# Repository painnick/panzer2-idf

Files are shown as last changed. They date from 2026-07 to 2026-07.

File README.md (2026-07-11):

# panzer2-idf

ESP32-C3 기반 RC 탱크 펌웨어입니다.  
BLE 게임패드로 **캐터필러 주행**, **터렛 회전**, **포/기관총 효과**, **DFPlayer 효과음**을 제어합니다.

Arduino/PlatformIO 프로젝트 **M3Stuart_ESP32C3** 를 ESP-IDF v5.5.2 로 포팅한 버전이며, 입력은 [Bluepad32](https://github.com/ricardoquesada/bluepad32) + BTstack 를 사용합니다.

## 기능

| 기능 | 설명 |
|---|---|
| 트랙 구동 | DRV8833, 좌/우 스틱 Y축 — panzer4식 가속/감속 램프(~1초 최대) |
| 터렛 | SG90 서보 — 패드 연결 시 attach, D-Pad 좌우 회전, 3초 무입력/해제 시 detach |
| 포신 | B 버튼 — LED·효과음 후 트랙 후진 리코일 |
| 게틀링(기관총) | A 버튼 — 게틀링 LED 깜빡임 + 효과음 |
| 볼륨 | L1 / R1, NVS에 저장 |
| 사운드 | DFPlayer Mini (대기 / 포 / 기관총 / 연결음) |

## 하드웨어

- **MCU**: ESP32-C3 (BLE only — Classic BT 미지원)
- **모터 드라이버**: DRV8833
- **서보**: SG90 (터렛)
- **오디오**: DFPlayer Mini + microSD
- **입력**: BLE HID 게임패드 (검증: GamePadPlus V3 / ShanWan BM-769)

### 핀맵

| 기능 | GPIO |
|---|---|
| 좌측 트랙 IN1 / IN2 | 4 / 3 |
| 우측 트랙 IN1 / IN2 | 0 / 5 |
| 포신 LED | 1 |
| 게틀링 LED | 6 |
| 터렛 서보 | 7 |
| DFPlayer TX / RX | 10 / 9 |

> GPIO20/21은 ESP32-C3 기본 UART0 콘솔용입니다. DFPlayer RX는 **GPIO9**를 사용합니다.

### PCB

회로 개략도는 `pcb/` 에 있습니다.

| 파일 | 설명 |
|---|---|
| `pcb/Schematic_M3-Stuart_2026-07-11.png` | M3 Stuart 스케매틱 |

### 3D 출력 (`3dp/`)

기구부 STEP 모델입니다. 슬라이서에서 열어 STL 등으로 변환해 출력하면 됩니다.

| 파일 | 설명 |
|---|---|
| `Idler.step` | 아이들러 |
| `Motor Guide 2mm.step` | 모터 가이드 2mm |
| `Motor Guide 3mm D.step` | 모터 가이드 3mm |
| `PCB 3.2.step` | PCB 브라켓 |
| `Sproket Guide.step` | 스프로킷 가이드 |
| `Turret.step` | 터렛 |

### DFPlayer 트랙 (SD 카드)

| 파일 | 용도 |
|---|---|
| `0001.mp3` | 대기 루프 |
| `0002.mp3` | 포신 발사 |
| `0003.mp3` | 기관총 |
| `0004.mp3` | 게임패드 연결 |

## 조작

| 입력 | 동작 |
|---|---|
| 좌 스틱 Y | 좌측 트랙 전/후진 (즉시 최대 아님, ~1초 램프 가속) |
| 우 스틱 Y | 우측 트랙 전/후진 (동일) |
| D-Pad ← / → | 터렛 좌/우 회전 (0°~180°, 약 120ms마다 1°) |
| Start | 터렛 서보 중앙(90°) |
| A | 게틀링(기관총) — LED 75ms 깜빡임, 약 0.5초 |
| B | 포신 — LED·효과음 후 리코일(후진) |
| L1 / R1 | 볼륨 감소 / 증가 |

### 터렛 서보

- **부팅**: 서보 미연결 (PWM 없음)
- **게임패드 연결 시**: 서보 attach 후 **중앙(90°)** 설정
- **게임패드 해제 시**: 서보 detach
- **회전 속도**: `TURRET_STEP_INTERVAL_MS`(기본 120ms)마다 1° — 전체 0°↔180°에 약 22초
- **무입력 해제**: D-Pad 터렛 입력이 `TURRET_IDLE_DISCONNECT_MS`(기본 **3초**) 없으면 detach (버즈·홀딩 전류 감소)
- **재연결**: D-Pad 좌/우로 각도를 바꿀 때 다시 attach

### 포 발사 시퀀스 (B)

1. 포신 LED ON + 포 효과음 재생
2. `RECOIL_DELAY_MS`(기본 250ms) 대기
3. 트랙 후진 리코일 (`RECOIL_BACK_DURATION` 40ms) → 정지 안정화 (`RECOIL_SETTLE_DURATION` 40ms)

스틱 전진이 음수 축이므로 리코일 후진은 양수 모터 속도(`RECOIL_BACK_SPEED`)를 사용합니다. 리코일 중에는 스틱 모터 입력을 잠시 무시합니다.

## 게임패드 연결 (중요)

ESP32-C3는 **BLE만** 지원합니다. DualShock 등 Classic BT 전용 패드는 연결되지 않습니다.

### GamePadPlus V3 / Terios T3 / ShanWan BM-769

1. 패드를 끈 뒤, **`Home + X`** 를 약 3초 눌러 페어링 모드로 진입 (표준 Android BLE HID)
2. 펌웨어 부팅 후 자동 스캔·연결
3. 성공 시 로그 예: `Gamepad ready (...), reports=2` → `게임패드 연결됨`

`Home + A` / `Home + Y` 모드는 BLE여도 HID 데이터 형식이 달라 동작하지 않을 수 있습니다.

### 연결 구현 메모

일부 저가 BLE 패드는 BTstack 기본 `hids_client` 경로에서 HID 설정이 멈추는 문제가 있습니다.  
이 프로젝트는 **Simple HOG** 경로를 사용합니다.

- GATT 서비스 탐색 → HID(0x1812) 특성 탐색
- Report Map 읽기
- CCC 직접 쓰기 + 알림 수신
- Report ID 프리펜드 후 Bluepad32 Android 파서로 입력 처리

부팅 시 본딩 키를 지우지 않습니다. 강제 재페어링이 필요하면 콘솔에서 키 삭제 명령을 사용하세요.

## 소프트웨어 구조

```
main/
  main.c           # 모터/서보/LED, 게임패드 처리, 제어 루프
  my_platform.c    # Bluepad32 커스텀 플랫폼, 공유 입력 상태
  dfplayer.c/.h    # DFPlayer Mini UART 제어
components/
  bluepad32/       # Bluepad32 (커스텀 Simple HOG 포함)
  btstack/         # BTstack ESP32 포트
```

- **bt_main**: BTstack 런 루프 (우선순위 높음)
- **tank_ctrl**: 10ms 주기로 게임패드 입력 → 액추에이터 반영

## 빌드 & 플래시

### 요구 사항

- [ESP-IDF v5.5.x](https://docs.espressif.com/projects/esp-idf/en/v5.5.2/esp32c3/get-started/index.html)
- 타깃: `esp32c3`

### 환경 설정 (Windows 예)

```bat
REM ESP-IDF export (경로는 설치에 맞게 수정)
call C:\Espressif\frameworks\esp-idf-v5.5.2\export.bat

cd panzer2-idf
idf.py set-target esp32c3
idf.py build
idf.py -p COMx flash monitor
```

`setup.bat` / `setup.sh` 로 Bluepad32·BTstack 의존성을 준비할 수 있습니다 (이미 `components/` 가 포함되어 있으면 생략 가능).

### 주요 sdkconfig

- BLE 컨트롤러 only (`CONFIG_BT_CONTROLLER_ONLY`)
- Wi-Fi 비활성
- Bluepad32 커스텀 플랫폼
- 기본 로그 레벨: INFO (상세 BLE 단계는 DEBUG)

## 라이선스 관련

- 애플리케이션 코드: 프로젝트 정책에 따름
- **Bluepad32**: Apache-2.0
- **BTstack**: 비상업 평가 가능, 상업 사용 시 [BlueKitchen](https://bluekitchen-gmbh.com/) 라이선스 필요

## 참고

- [Bluepad32 문서](https://bluepad32.readthedocs.io/)
- [ESP-IDF](https://docs.espressif.com/projects/esp-idf/)
- 원본: M3Stuart_ESP32C3 (Arduino/PlatformIO)

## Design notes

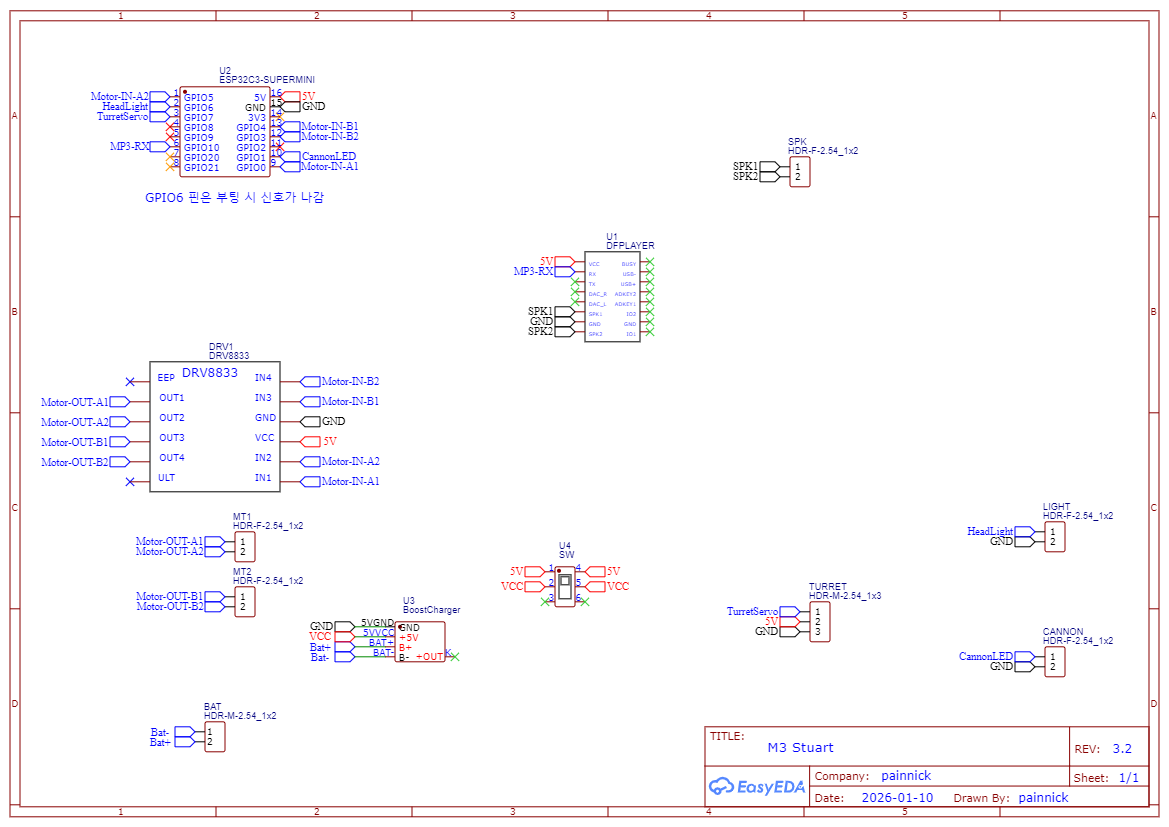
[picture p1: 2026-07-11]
pcb/Schematic_M3-Stuart_2026-07-11.png

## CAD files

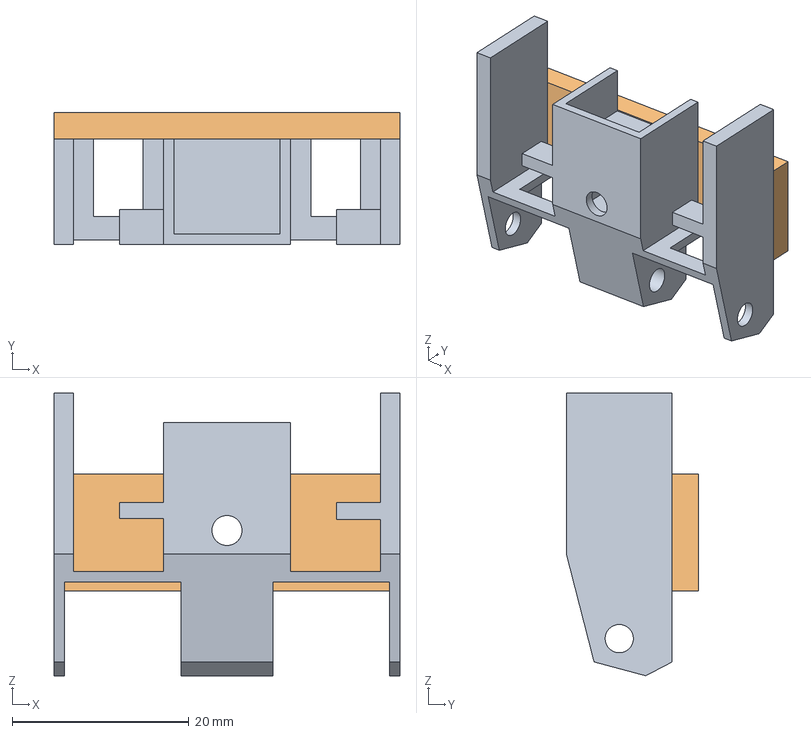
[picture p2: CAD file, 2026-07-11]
3dp/Sproket Guide.step
39.2 x 15.0 x 32.0 mm

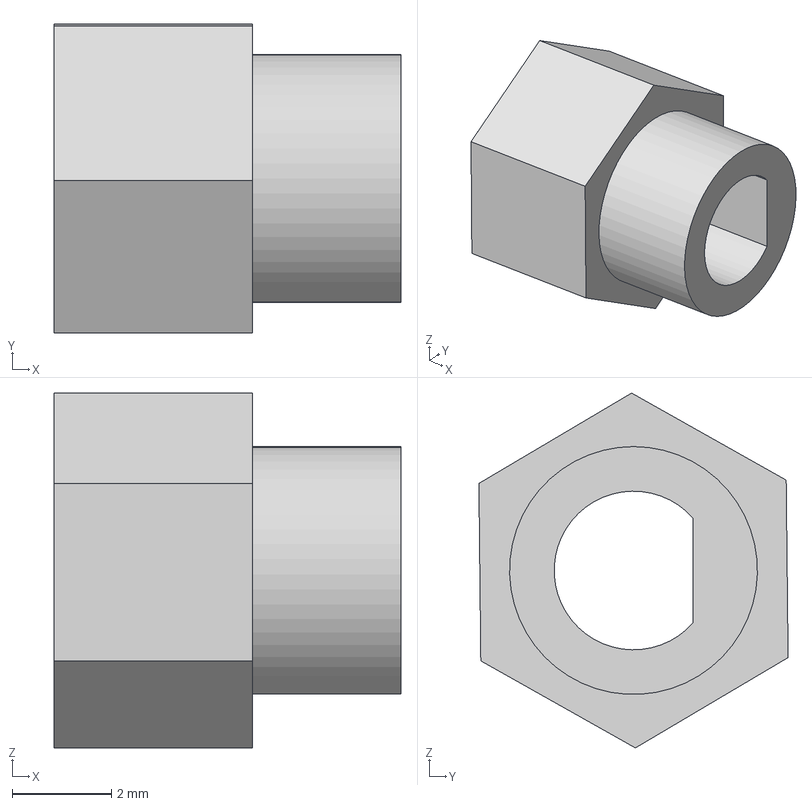
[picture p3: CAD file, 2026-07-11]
3dp/Motor Guide 3mm D.step
7.00 x 6.24 x 7.16 mm

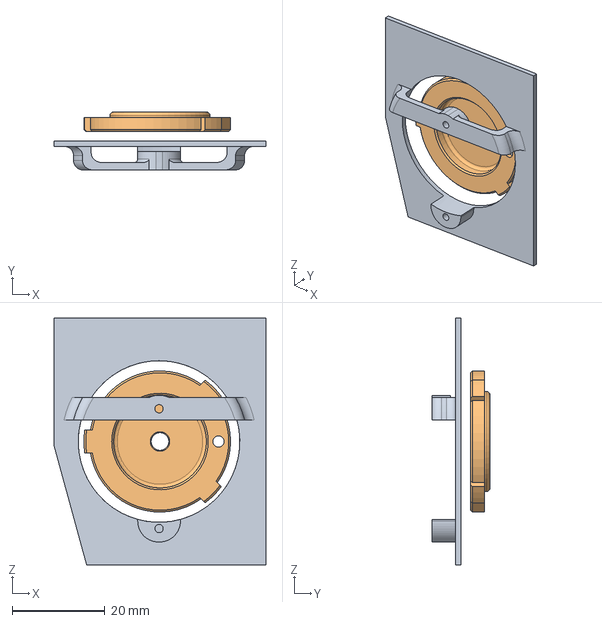
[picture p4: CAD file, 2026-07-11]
3dp/Turret.step
45.6 x 12.5 x 53.2 mm
Cover

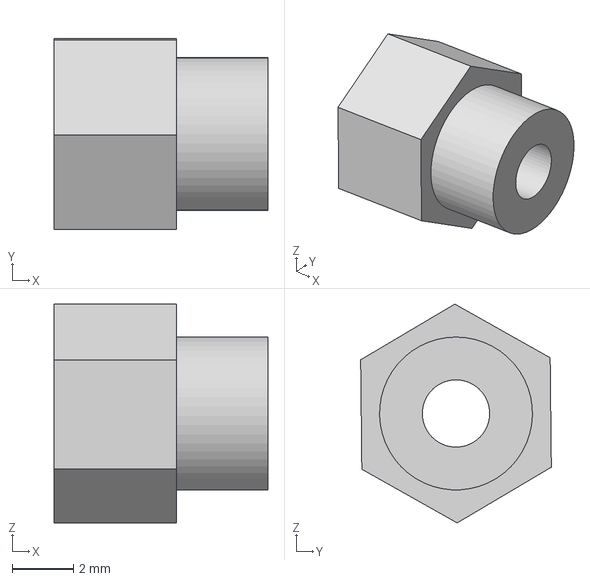
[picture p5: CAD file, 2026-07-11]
3dp/Motor Guide 2mm.step
7.00 x 6.24 x 7.16 mm

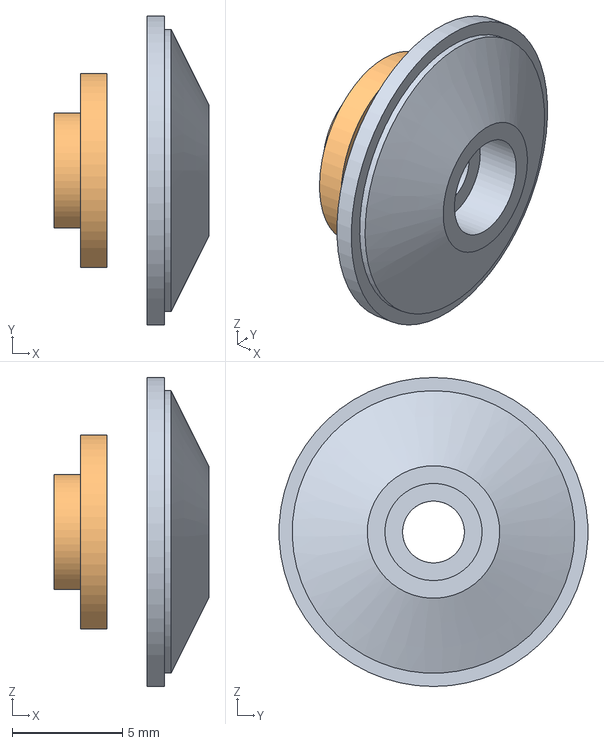
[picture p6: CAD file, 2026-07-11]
3dp/Idler.step
7.00 x 14.0 x 14.0 mm

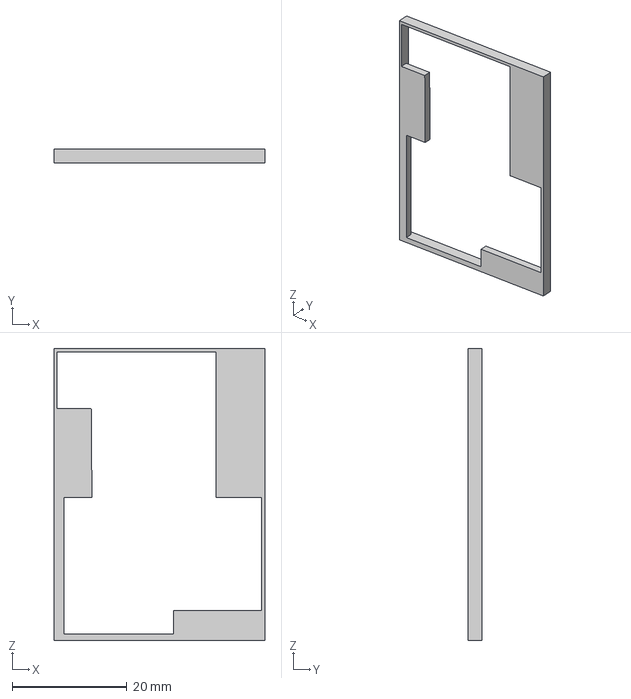
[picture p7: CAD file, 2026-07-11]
3dp/PCB 3.2.step
36.7 x 2.40 x 50.8 mm

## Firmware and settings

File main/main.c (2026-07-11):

// RC 탱크 - ESP-IDF v5.5.2
// Original: M3Stuart_ESP32C3 (Arduino/PlatformIO)
//
// Bluepad32 게임패드로 DRV8833 모터 트랙 + SG90 서보 터렛 + DFPlayer 효과음 제어

#include <string.h>
#include <math.h>

#include "freertos/FreeRTOS.h"
#include "freertos/task.h"
#include "esp_log.h"
#include "esp_timer.h"
#include "nvs_flash.h"
#include "nvs.h"
#include "driver/gpio.h"
#include "driver/ledc.h"

#include "btstack_port_esp32.h"
#include "dfplayer.h"
#include "btstack_run_loop.h"
#include "uni.h"

// my_platform.c
struct uni_platform* get_my_platform(void);
void gamepad_state_init(void);

static const char* TAG = "RC_TANK";

// ============================================================================
// 핀 정의
// ============================================================================
#define PIN_LEFT_IN1        4   // DRV8833 좌측 트랙 IN1
#define PIN_LEFT_IN2        3   // DRV8833 좌측 트랙 IN2
#define PIN_RIGHT_IN1       0   // DRV8833 우측 트랙 IN1
#define PIN_RIGHT_IN2       5   // DRV8833 우측 트랙 IN2
#define PIN_CANNON_LED      1   // 포신 LED
#define PIN_MG_LED          6   // 게틀링(기관총) LED
#define PIN_TURRET_SERVO    7   // 터렛 SG90 서보

// ============================================================================
// LEDC 채널/타이머 할당
// ============================================================================
#define LEDC_MOTOR_FREQ     5000
#define LEDC_MOTOR_RES      LEDC_TIMER_8_BIT
#define LEDC_SERVO_FREQ     50
#define LEDC_SERVO_RES      LEDC_TIMER_14_BIT

#define LEDC_CH_LEFT_IN1    LEDC_CHANNEL_0
#define LEDC_CH_LEFT_IN2    LEDC_CHANNEL_1
#define LEDC_CH_RIGHT_IN1   LEDC_CHANNEL_2
#define LEDC_CH_RIGHT_IN2   LEDC_CHANNEL_3
#define LEDC_CH_SERVO       LEDC_CHANNEL_4

#define LEDC_TIMER_MOTOR    LEDC_TIMER_0
#define LEDC_TIMER_SERVO    LEDC_TIMER_1

// ============================================================================
// NVS 키
// ============================================================================
#define NVS_NAMESPACE       "rc_tank"
#define NVS_KEY_VOLUME      "volume"

// ============================================================================
// 타이밍 상수 (ms)
// ============================================================================
#define LOOP_INTERVAL_MS        10
#define IDLE_SOUND_INTERVAL_MS  13000
#define VOLUME_CHANGE_INTERVAL  100
#define BUTTON_SWAP_HOLD_MS     3000
#define EEPROM_RESET_HOLD_MS    3000
#define CANNON_LED_DURATION     200
#define MACHINE_GUN_DURATION    500   // panzer4 MG_FIRE_MS
#define MG_LED_BLINK_MS         75    // panzer4 게틀링 LED 깜빡임 주기
#define TURRET_STEP_INTERVAL_MS 120   // 터렛 1° 이동 간격 (ms) — 아주 느리게
#define TURRET_IDLE_DISCONNECT_MS 3000 // 터렛 무입력 시 서보 연결 해제 (ms)
#define GAMEPAD_CONNECT_GRACE_MS  500 // 연결 직후 입력 무시 (노이즈/잔여 D-Pad 방지)
#define RECOIL_DELAY_MS         250   // LED·효과음 후 반동 시작 지연 (ms)
#define RECOIL_BACK_DURATION    40    // 포 발사 시 후진 시간 (ms)
#define RECOIL_SETTLE_DURATION  40    // 후진 후 정지 안정화 (ms)

// ============================================================================
// 모터 설정 (panzer4: 램프 가속/감속)
// ============================================================================
// 기동 최소 속도 (0~512). 너무 낮으면 고주파 윙 소리만 나고 바퀴가 안 돔.
// duty ≈ START * 255 / 512 → 400 ≈ 78%
#define MOTOR_START_SPEED   400
#define MOTOR_MAX_SPEED     512
#define LEDC_MOTOR_DUTY_MAX 255   // 8-bit LEDC
// 내부 속도 = 실제 속도 * TRACK_SPEED_SCALE (10ms마다 step)
// 기동(START)→max 약 1초, max→정지 약 0.4초
#define TRACK_SPEED_SCALE   10
#define TRACK_ACCEL_STEP    12    // 10ms당 가속 (×10 스케일)
#define TRACK_DECEL_STEP    100   // 10ms당 감속 (×10 스케일)
// 스틱 전진 = axis_y 음수 → 후진 반동은 양수 최대 속도
#define RECOIL_BACK_SPEED   MOTOR_MAX_SPEED

// ============================================================================
// 외부 함수 선언 (my_platform.c)
// ============================================================================
extern bool gamepad_is_connected(void);
extern bool gamepad_read_new_connection(void);
extern bool gamepad_read(int32_t* axis_y, int32_t* axis_ry, uint16_t* buttons,
                         uint8_t* dpad, uint8_t* misc_buttons);

// ============================================================================
// 전역 상태
// ============================================================================

// NVS
static nvs_handle_t g_nvs_handle;

// DFPlayer
static int g_current_volume = 20;
static int g_temp_volume = 20;

// 트랙 모터 (목표 속도 vs 램프 현재 속도)
static int g_target_left_speed = 0;
static int g_target_right_speed = 0;
static int g_current_left_x10 = 0;
static int g_current_right_x10 = 0;

// 터렛 서보
static int g_turret_angle = 90;
static int64_t g_turret_last_step_ms = 0;
static int64_t g_turret_last_input_ms = 0;
static bool g_turret_attached = false;

// 게임패드 연결 직후 입력 무시 시각
static int64_t g_input_ignore_until_ms = 0;

// 포신 발사
static bool g_cannon_firing = false;
static int64_t g_cannon_start_time = 0;

// 리코일 (pending: LED/효과음 대기 → active: 후진/안정화)
static bool g_recoil_pending = false;
static bool g_recoil_active = false;
static int64_t g_recoil_start_time = 0;

// 기관총(게틀링)
static bool g_machinegun_firing = false;
static int64_t g_machinegun_start_time = 0;
static bool g_mg_led_on = false;
static int64_t g_mg_led_last_toggle = 0;

// 효과음
static int64_t g_last_idle_sound_time = 0;

// 볼륨 조절
static bool g_l1_pressed = false;
static bool g_r1_pressed = false;
static int64_t g_l1_last_change = 0;
static int64_t g_r1_last_change = 0;
static bool g_volume_changed = false;

// Start 버튼 (터렛 중앙) 엣지 감지
static bool g_start_pressed = false;

// 현재 시간 (us)
static inline int64_t now_us(void) {
    return esp_timer_get_time();
}

static inline int64_t now_ms(void) {
    return now_us() / 1000;
}

// ============================================================================
// NVS 볼륨 관리
// ============================================================================
static void load_volume_from_nvs(void) {
    int32_t stored = -1;
    esp_err_t err = nvs_get_i32(g_nvs_handle, NVS_KEY_VOLUME, &stored);
    if (err != ESP_OK || stored < 11 || stored > 30) {
        stored = 20;
        ESP_LOGI(TAG, "NVS 볼륨 없음, 기본값 사용: %d", stored);
    } else {
        ESP_LOGI(TAG, "NVS 볼륨 로드: %d", stored);
    }
    g_current_volume = (int)stored;
    g_temp_volume = (int)stored;
}

static void save_volume_to_nvs(int vol) {
    int32_t clamped = vol;
    if (clamped < 11) clamped = 11;
    if (clamped > 30) clamped = 30;
    nvs_set_i32(g_nvs_handle, NVS_KEY_VOLUME, clamped);
    nvs_commit(g_nvs_handle);
    ESP_LOGI(TAG, "NVS 볼륨 저장: %d", clamped);
}

// ============================================================================
// LEDC 초기화
// ============================================================================

// 채널별 GPIO 매핑 테이블
typedef struct {
    gpio_num_t gpio;
    ledc_channel_t channel;
} motor_pin_map_t;

static const motor_pin_map_t g_motor_pins[] = {
    { .gpio = PIN_LEFT_IN1,  .channel = LEDC_CH_LEFT_IN1  },
    { .gpio = PIN_LEFT_IN2,  .channel = LEDC_CH_LEFT_IN2  },
    { .gpio = PIN_RIGHT_IN1, .channel = LEDC_CH_RIGHT_IN1 },
    { .gpio = PIN_RIGHT_IN2, .channel = LEDC_CH_RIGHT_IN2 },
};

static void init_ledc(void) {
    // 모터 타이머: 5kHz, 8-bit
    ledc_timer_config_t motor_timer = {
        .speed_mode = LEDC_LOW_SPEED_MODE,
        .duty_resolution = LEDC_MOTOR_RES,
        .timer_num = LEDC_TIMER_MOTOR,
        .freq_hz = LEDC_MOTOR_FREQ,
        .clk_cfg = LEDC_AUTO_CLK,
    };
    ledc_timer_config(&motor_timer);

    // 모터 채널 초기화
    for (int i = 0; i < 4; i++) {
        ledc_channel_config_t ch = {
            .speed_mode = LEDC_LOW_SPEED_MODE,
            .channel = g_motor_pins[i].channel,
            .timer_sel = LEDC_TIMER_MOTOR,
            .gpio_num = g_motor_pins[i].gpio,
            .duty = 0,
            .hpoint = 0,
        };
        ledc_channel_config(&ch);
    }

    // 서보 타이머: 50Hz, 14-bit (채널은 입력 시 attach)
    ledc_timer_config_t servo_timer = {
        .speed_mode = LEDC_LOW_SPEED_MODE,
        .duty_resolution = LEDC_SERVO_RES,
        .timer_num = LEDC_TIMER_SERVO,
        .freq_hz = LEDC_SERVO_FREQ,
        .clk_cfg = LEDC_AUTO_CLK,
    };
    ledc_timer_config(&servo_timer);
}

// ============================================================================
// 모터 제어 (panzer4식 가속/감속 램프)
// ============================================================================
static void apply_motor_pwm(ledc_channel_t ch_in1, ledc_channel_t ch_in2, int speed) {
    int abs_sp = abs(speed);
    if (abs_sp == 0) {
        ledc_set_duty(LEDC_LOW_SPEED_MODE, ch_in1, 0);
        ledc_update_duty(LEDC_LOW_SPEED_MODE, ch_in1);
        ledc_set_duty(LEDC_LOW_SPEED_MODE, ch_in2, 0);
        ledc_update_duty(LEDC_LOW_SPEED_MODE, ch_in2);
        return;
    }

    if (abs_sp > MOTOR_MAX_SPEED) abs_sp = MOTOR_MAX_SPEED;
    // 저속 구간은 기동 토크 확보 (윙 소리만 나는 구간 회피)
    if (abs_sp < MOTOR_START_SPEED) abs_sp = MOTOR_START_SPEED;

    uint32_t duty = (uint32_t)abs_sp * LEDC_MOTOR_DUTY_MAX / MOTOR_MAX_SPEED;
    if (duty > LEDC_MOTOR_DUTY_MAX) duty = LEDC_MOTOR_DUTY_MAX;

    if (speed > 0) {
        ledc_set_duty(LEDC_LOW_SPEED_MODE, ch_in1, duty);
        ledc_update_duty(LEDC_LOW_SPEED_MODE, ch_in1);
        ledc_set_duty(LEDC_LOW_SPEED_MODE, ch_in2, 0);
        ledc_update_duty(LEDC_LOW_SPEED_MODE, ch_in2);
    } else {
        ledc_set_duty(LEDC_LOW_SPEED_MODE, ch_in1, 0);
        ledc_update_duty(LEDC_LOW_SPEED_MODE, ch_in1);
        ledc_set_duty(LEDC_LOW_SPEED_MODE, ch_in2, duty);
        ledc_update_duty(LEDC_LOW_SPEED_MODE, ch_in2);
    }
}

// panzer4: 0 기동 시 START 점프, 가속/감속 step, 정지 시 START 이하 → 0
static void update_track_speed_x10(int* current_x10, int target) {
    int cur = *current_x10;
    int target_x10 = target * TRACK_SPEED_SCALE;
    int min_x10 = MOTOR_START_SPEED * TRACK_SPEED_SCALE;

    if (cur == target_x10) {
        return;
    }

    if (cur == 0 && target_x10 != 0) {
        int sign = (target_x10 > 0) ? 1 : -1;
        int start = sign * min_x10;
        int target_abs = (target_x10 > 0) ? target_x10 : -target_x10;
        if (target_abs <= min_x10) {
            *current_x10 = target_x10;
            return;
        }
        cur = start;
        *current_x10 = cur;
    }

    int diff = target_x10 - cur;
    bool is_decelerating = false;
    if (cur > 0) {
        if (target_x10 < cur) is_decelerating = true;
    } else if (cur < 0) {
        if (target_x10 > cur) is_decelerating = true;
    }

    int step = is_decelerating ? TRACK_DECEL_STEP : TRACK_ACCEL_STEP;
    if (diff > 0) {
        *current_x10 = (diff > step) ? (cur + step) : target_x10;
    } else {
        *current_x10 = (-diff > step) ? (cur - step) : target_x10;
    }

    if (target_x10 == 0) {
        int cur_abs = (*current_x10 > 0) ? *current_x10 : -*current_x10;
        if (cur_abs < min_x10) {
            *current_x10 = 0;
        }
    }
}

// 스틱 값 → 목표 속도. 0이 아니면 최소 MOTOR_START_SPEED 보장.
static int clamp_track_target(int v) {
    if (v > MOTOR_MAX_SPEED) v = MOTOR_MAX_SPEED;
    if (v < -MOTOR_MAX_SPEED) v = -MOTOR_MAX_SPEED;
    if (v != 0 && abs(v) < MOTOR_START_SPEED) {
        v = (v > 0) ? MOTOR_START_SPEED : -MOTOR_START_SPEED;
    }
    return v;
}

static void set_track_targets(int left, int right) {
    g_target_left_speed = clamp_track_target(left);
    g_target_right_speed = clamp_track_target(right);
}

// 리코일·비상 정지 등 램프 우회
static void set_track_immediate(int left, int right) {
    if (left > MOTOR_MAX_SPEED) left = MOTOR_MAX_SPEED;
    if (left < -MOTOR_MAX_SPEED) left = -MOTOR_MAX_SPEED;
    if (right > MOTOR_MAX_SPEED) right = MOTOR_MAX_SPEED;
    if (right < -MOTOR_MAX_SPEED) right = -MOTOR_MAX_SPEED;
    g_target_left_speed = left;
    g_target_right_speed = right;
    g_current_left_x10 = left * TRACK_SPEED_SCALE;
    g_current_right_x10 = right * TRACK_SPEED_SCALE;
    apply_motor_pwm(LEDC_CH_LEFT_IN1, LEDC_CH_LEFT_IN2, left);
    apply_motor_pwm(LEDC_CH_RIGHT_IN1, LEDC_CH_RIGHT_IN2, right);
}

static void process_motor_ramp(void) {
    if (g_recoil_active) return;

    update_track_speed_x10(&g_current_left_x10, g_target_left_speed);
    update_track_speed_x10(&g_current_right_x10, g_target_right_speed);
    apply_motor_pwm(LEDC_CH_LEFT_IN1, LEDC_CH_LEFT_IN2,
                    g_current_left_x10 / TRACK_SPEED_SCALE);
    apply_motor_pwm(LEDC_CH_RIGHT_IN1, LEDC_CH_RIGHT_IN2,
                    g_current_right_x10 / TRACK_SPEED_SCALE);
}

// ============================================================================
// 서보 제어 (무입력 시 연결 해제 → 버즈/전류 감소)
// ============================================================================
static void turret_apply_pwm(int angle) {
    if (angle < 0) angle = 0;
    if (angle > 180) angle = 180;
    // 0.5ms(0도) ~ 2.5ms(180도) in 14-bit (0~16383) at 50Hz(20ms)
    // 0.5ms = 409, 2.5ms = 2048
    uint32_t duty = 409 + (uint32_t)((int32_t)angle * (2048 - 409) / 180);
    ledc_set_duty(LEDC_LOW_SPEED_MODE, LEDC_CH_SERVO, duty);
    ledc_update_duty(LEDC_LOW_SPEED_MODE, LEDC_CH_SERVO);
}

static void turret_attach(void) {
    if (g_turret_attached) return;

    ledc_channel_config_t servo_ch = {
        .speed_mode = LEDC_LOW_SPEED_MODE,
        .channel = LEDC_CH_SERVO,
        .timer_sel = LEDC_TIMER_SERVO,
        .gpio_num = PIN_TURRET_SERVO,
        .duty = 0,
        .hpoint = 0,
    };
    ledc_channel_config(&servo_ch);
    g_turret_attached = true;
    turret_apply_pwm(g_turret_angle);
    ESP_LOGD(TAG, "터렛 서보 연결");
}

static void turret_detach(void) {
    if (!g_turret_attached) return;

    ledc_stop(LEDC_LOW_SPEED_MODE, LEDC_CH_SERVO, 0);
    gpio_reset_pin(PIN_TURRET_SERVO);
    g_turret_attached = false;
    ESP_LOGD(TAG, "터렛 서보 연결 해제");
}

static void set_turret_angle(int angle) {
    if (angle < 0) angle = 0;
    if (angle > 180) angle = 180;
    g_turret_angle = angle;

    if (!g_turret_attached) {
        turret_attach();
    } else {
        turret_apply_pwm(g_turret_angle);
    }
}

static void process_turret_idle(void) {
    if (!g_turret_attached) return;
    if (now_ms() - g_turret_last_input_ms >= TURRET_IDLE_DISCONNECT_MS) {
        turret_detach();
    }
}

// ============================================================================
// 게임패드 처리
// ============================================================================
static void process_gamepad(int32_t axis_y, int32_t axis_ry,
                            uint16_t buttons, uint8_t dpad, uint8_t misc_buttons) {
    // 연결 직후 grace: 잔여 D-Pad/버튼으로 터렛·모터가 움직이지 않게
    if (now_ms() < g_input_ignore_until_ms) {
        if (!g_recoil_active) {
            set_track_targets(0, 0);
        }
        return;
    }

    // 데드존
    int left_y = (abs(axis_y) < 50) ? 0 : (int)axis_y;
    int right_y = (abs(axis_ry) < 50) ? 0 : (int)axis_ry;

    // 목표 속도만 설정 — 실제 PWM은 process_motor_ramp()가 가속/감속
    if (!g_recoil_active) {
        set_track_targets(left_y, right_y);
    }

    // D-PAD 좌우: 터렛 회전
    // - 각도 변경 시에만 attach (연결 직후 PWM 재인가로 위치가 튀는 것 방지)
    // - 이미 attach된 상태에서 홀드 중이면 idle 타이머만 갱신
    if ((dpad & DPAD_LEFT) || (dpad & DPAD_RIGHT)) {
        int64_t now = now_ms();
        if (g_turret_attached) {
            g_turret_last_input_ms = now;
        }
        if (now - g_turret_last_step_ms >= TURRET_STEP_INTERVAL_MS) {
            if (dpad & DPAD_LEFT) {
                if (g_turret_angle > 0) {
                    g_turret_last_step_ms = now;
                    g_turret_last_input_ms = now;
                    set_turret_angle(g_turret_angle - 1);
                }
            } else if (dpad & DPAD_RIGHT) {
                if (g_turret_angle < 180) {
                    g_turret_last_step_ms = now;
                    g_turret_last_input_ms = now;
                    set_turret_angle(g_turret_angle + 1);
                }
            }
        }
    }

    // Start: 터렛 서보 중앙(90°)
    if (misc_buttons & MISC_BUTTON_START) {
        if (!g_start_pressed) {
            g_start_pressed = true;
            g_turret_last_input_ms = now_ms();
            set_turret_angle(90);
        }
    } else {
        g_start_pressed = false;
    }

    // B 버튼: LED·효과음 먼저, 반동은 RECOIL_DELAY_MS 후 process_recoil()
    if ((buttons & BUTTON_B) && !g_cannon_firing && !g_machinegun_firing
            && !g_recoil_pending && !g_recoil_active) {
        g_cannon_firing = true;
        g_cannon_start_time = now_ms();
        gpio_set_level(PIN_CANNON_LED, 1);
        dfplayer_play(DFPLAYER_TRACK_CANNON);

        g_recoil_pending = true;
        g_recoil_start_time = now_ms();
    }

    // A 버튼: 기관총(게틀링) 발사 — LED 깜빡임 + 효과음
    if ((buttons & BUTTON_A) && !g_machinegun_firing && !g_cannon_firing) {
        g_machinegun_firing = true;
        g_machinegun_start_time = now_ms();
        g_mg_led_on = true;
        g_mg_led_last_toggle = now_ms();
        gpio_set_level(PIN_MG_LED, 1);
        dfplayer_play(DFPLAYER_TRACK_MACHINEGUN);
    }

    // L1: 볼륨 감소
    if (buttons & BUTTON_SHOULDER_L) {
        if (!g_l1_pressed) {
            g_l1_pressed = true;
            g_temp_volume = g_current_volume;
            g_l1_last_change = now_ms();
        }
        if (g_temp_volume > 11 && (now_ms() - g_l1_last_change >= VOLUME_CHANGE_INTERVAL)) {
            g_temp_volume--;
            g_l1_last_change = now_ms();
        }
    } else {
        if (g_l1_pressed) {
            g_l1_pressed = false;
            if (g_temp_volume != g_current_volume) {
                g_current_volume = g_temp_volume;
                dfplayer_set_volume(g_current_volume);
                g_volume_changed = true;
            }
        }
    }

    // R1: 볼륨 증가
    if (buttons & BUTTON_SHOULDER_R) {
        if (!g_r1_pressed) {
            g_r1_pressed = true;
            g_temp_volume = g_current_volume;
            g_r1_last_change = now_ms();
        }
        if (g_temp_volume < 30 && (now_ms() - g_r1_last_change >= VOLUME_CHANGE_INTERVAL)) {
            g_temp_volume++;
            g_r1_last_change = now_ms();
        }
    } else {
        if (g_r1_pressed) {
            g_r1_pressed = false;
            if (g_temp_volume != g_current_volume) {
                g_current_volume = g_temp_volume;
                dfplayer_set_volume(g_current_volume);
                g_volume_changed = true;
            }
        }
    }

    // 볼륨 변경 시 NVS 저장
    if (g_volume_changed) {
        save_volume_to_nvs(g_current_volume);
        g_volume_changed = false;
    }
}

// ============================================================================
// 타이머 기반 처리
// ============================================================================
static void process_cannon_firing(void) {
    if (!g_cannon_firing) return;
    if (now_ms() - g_cannon_start_time >= CANNON_LED_DURATION) {
        g_cannon_firing = false;
        gpio_set_level(PIN_CANNON_LED, 0);
    }
}

// panzer4: MG_LED_BLINK_MS 주기로 토글, MG_FIRE_MS 후 소등
static void process_machinegun_firing(void) {
    if (!g_machinegun_firing) return;

    int64_t now = now_ms();
    if (now - g_machinegun_start_time >= MACHINE_GUN_DURATION) {
        g_machinegun_firing = false;
        g_mg_led_on = false;
        gpio_set_level(PIN_MG_LED, 0);
        return;
    }

    if (now - g_mg_led_last_toggle >= MG_LED_BLINK_MS) {
        g_mg_led_last_toggle = now;
        g_mg_led_on = !g_mg_led_on;
        gpio_set_level(PIN_MG_LED, g_mg_led_on ? 1 : 0);
    }
}
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
void app_main(void) {
    // 모니터 연결 직후에도 바로 보이도록 즉시 로그
    // 캐패시터 충전 대기
    vTaskDelay(pdMS_TO_TICKS(2000));

    ESP_LOGI(TAG, "RC Tank 초기화 시작");

    // NVS 초기화
    esp_err_t ret = nvs_flash_init();
    if (ret == ESP_ERR_NVS_NO_FREE_PAGES || ret == ESP_ERR_NVS_NEW_VERSION_FOUND) {
        nvs_flash_erase();
        nvs_flash_init();
    }
    nvs_open(NVS_NAMESPACE, NVS_READWRITE, &g_nvs_handle);
    load_volume_from_nvs();

    // GPIO 초기화
    gpio_reset_pin(PIN_LEFT_IN1);
    gpio_reset_pin(PIN_LEFT_IN2);
    gpio_reset_pin(PIN_RIGHT_IN1);
    gpio_reset_pin(PIN_RIGHT_IN2);
    gpio_reset_pin(PIN_CANNON_LED);
    gpio_reset_pin(PIN_MG_LED);
    // 터렛 서보는 게임패드 연결 시 attach (부팅 시 PWM/출력 설정 안 함)
    gpio_reset_pin(PIN_TURRET_SERVO);

    gpio_set_direction(PIN_LEFT_IN1, GPIO_MODE_OUTPUT);
    gpio_set_direction(PIN_LEFT_IN2, GPIO_MODE_OUTPUT);
    gpio_set_direction(PIN_RIGHT_IN1, GPIO_MODE_OUTPUT);
    gpio_set_direction(PIN_RIGHT_IN2, GPIO_MODE_OUTPUT);
    gpio_set_direction(PIN_CANNON_LED, GPIO_MODE_OUTPUT);
    gpio_set_direction(PIN_MG_LED, GPIO_MODE_OUTPUT);

    gpio_set_level(PIN_LEFT_IN1, 0);
    gpio_set_level(PIN_LEFT_IN2, 0);
    gpio_set_level(PIN_RIGHT_IN1, 0);
    gpio_set_level(PIN_RIGHT_IN2, 0);
    gpio_set_level(PIN_CANNON_LED, 0);
    gpio_set_level(PIN_MG_LED, 0);

    // LEDC 초기화 (서보 채널은 패드 연결 시 turret_attach)
    init_ledc();

    // DFPlayer 초기화 (실패해도 탱크/BT는 계속)
    if (dfplayer_init() != ESP_OK) {
        ESP_LOGW(TAG, "DFPlayer init failed — continuing without sound");
    } else {
        dfplayer_set_volume(g_current_volume);
        vTaskDelay(pdMS_TO_TICKS(200));
        dfplayer_play_loop(DFPLAYER_TRACK_IDLE);
        g_last_idle_sound_time = now_ms();
    }

    ESP_LOGI(TAG, "초기화 완료 — BTstack 시작");

    // 게임패드 상태 뮤프스 생성 (BTstack보다 먼저)
    gamepad_state_init();

    // 제어 태스크 (BTstack보다 낮은 우선순위 — ESP32-C3 단일 코어에서 BLE 안정성)
    xTaskCreate(control_task, "tank_ctrl", 4096, NULL, 4, NULL);

    // BTstack 메인 태스크 (높은 우선순위, 코어 0)
    xTaskCreatePinnedToCore(bt_main_task, "bt_main", 8192, NULL, 10, NULL, 0);
}

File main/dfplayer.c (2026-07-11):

/**
 * @file dfplayer.c
 * @brief DFPlayer Mini UART 제어 (panzer4-idf rctank_dfplayer 기반)
 */
#include "dfplayer.h"

#include "driver/uart.h"
#include "esp_log.h"
#include "freertos/FreeRTOS.h"
#include "freertos/task.h"

static const char* TAG = "dfplayer";

/* 핀 설정 (ESP32-C3)
 * 주의: GPIO20 = 기본 UART0 RX (콘솔). DFPlayer RX로 쓰면 시리얼 로그가 끊길 수 있음.
 * GPIO21 = 기본 UART0 TX. 둘 다 피한다.
 */
#define PIN_DFPLAYER_TX  10
#define PIN_DFPLAYER_RX  9

#define UART_NUM         UART_NUM_1
#define UART_BAUD        9600
#define UART_BUF_SIZE    256

/* DFPlayer 패킷 상수 */
#define DFPLAYER_SB          0x7E
#define DFPLAYER_VER         0xFF
#define DFPLAYER_LEN         0x06
#define DFPLAYER_NO_FEEDBACK 0x00
#define DFPLAYER_EB          0xEF

/* 명령 코드 */
#define DFPLAYER_CMD_PLAY           0x03
#define DFPLAYER_CMD_VOLUME         0x06
#define DFPLAYER_CMD_PLAYBACK_MODE  0x08
#define DFPLAYER_CMD_STOP           0x16

#define DFPLAYER_STACK_SIZE 10

typedef struct {
    uint8_t start_byte;
    uint8_t version;
    uint8_t length;
    uint8_t command_value;
    uint8_t feedback_value;
    uint8_t param_msb;
    uint8_t param_lsb;
    uint8_t checksum_msb;
    uint8_t checksum_lsb;
    uint8_t end_byte;
} dfplayer_stack_t;

static void dfplayer_find_checksum(dfplayer_stack_t* stack) {
    uint16_t sum = (uint16_t)(stack->version + stack->length + stack->command_value
                              + stack->feedback_value + stack->param_msb + stack->param_lsb);
    uint16_t checksum = (uint16_t)((~sum) + 1);
    stack->checksum_msb = (uint8_t)(checksum >> 8);
    stack->checksum_lsb = (uint8_t)(checksum & 0xFF);
}

static esp_err_t dfplayer_send_stack(const dfplayer_stack_t* stack) {
    uint8_t buf[DFPLAYER_STACK_SIZE] = {
        stack->start_byte, stack->version, stack->length,
        stack->command_value, stack->feedback_value,
        stack->param_msb, stack->param_lsb,
        stack->checksum_msb, stack->checksum_lsb, stack->end_byte,
    };
    int n = uart_write_bytes(UART_NUM, buf, DFPLAYER_STACK_SIZE);
    return (n == DFPLAYER_STACK_SIZE) ? ESP_OK : ESP_FAIL;
}

static esp_err_t dfplayer_send_cmd(uint8_t cmd, uint8_t param_msb, uint8_t param_lsb) {
    dfplayer_stack_t stack = {
        .start_byte = DFPLAYER_SB,
        .version = DFPLAYER_VER,
        .length = DFPLAYER_LEN,
        .command_value = cmd,
        .feedback_value = DFPLAYER_NO_FEEDBACK,
        .param_msb = param_msb,
        .param_lsb = param_lsb,
        .end_byte = DFPLAYER_EB,
    };
    dfplayer_find_checksum(&stack);
    return dfplayer_send_stack(&stack);
}

static bool dfplayer_verify_checksum(const dfplayer_stack_t* stack) {
    uint16_t sum = (uint16_t)(stack->version + stack->length + stack->command_value
                              + stack->feedback_value + stack->param_msb + stack->param_lsb);
    uint16_t checksum = (uint16_t)((~sum) + 1);
    return (stack->checksum_msb == (uint8_t)(checksum >> 8)) &&
           (stack->checksum_lsb == (uint8_t)(checksum & 0xFF));
}

/**
 * RX 태스크: DFPlayer 응답 수신, 트랙 완료 시 대기음 재생
 */
static void dfplayer_task(void* arg) {
    (void)arg;
    uint8_t data[128];
    uint8_t pkt_buf[DFPLAYER_STACK_SIZE];
    int pkt_idx = 0;

    while (1) {
        int len = uart_read_bytes(UART_NUM, data, sizeof(data), pdMS_TO_TICKS(50));
        if (len > 0) {
            for (int i = 0; i < len; i++) {
                uint8_t b = data[i];
                if (pkt_idx == 0) {
                    if (b == DFPLAYER_SB) {
                        pkt_buf[pkt_idx++] = b;
                    }
                } else {
                    pkt_buf[pkt_idx++] = b;
                    if (pkt_idx >= DFPLAYER_STACK_SIZE) {
                        if (pkt_buf[9] == DFPLAYER_EB) {
                            dfplayer_stack_t* s = (dfplayer_stack_t*)pkt_buf;
                            if (dfplayer_verify_checksum(s)) {
                                /* 0x3D = Track Finished */
                                if (s->command_value == 0x3D) {
                                    dfplayer_play_loop(DFPLAYER_TRACK_IDLE);
                                }
                            }
                        }
                        pkt_idx = 0;
                    }
                }
            }
        }
    }
}

esp_err_t dfplayer_init(void) {
    uart_config_t uart_config = {
        .baud_rate = UART_BAUD,
        .data_bits = UART_DATA_8_BITS,
        .parity = UART_PARITY_DISABLE,
        .stop_bits = UART_STOP_BITS_1,
        .flow_ctrl = UART_HW_FLOWCTRL_DISABLE,
        .source_clk = UART_SCLK_APB,
    };
    esp_err_t ret = uart_param_config(UART_NUM, &uart_config);
    if (ret != ESP_OK) return ret;
    ret = uart_set_pin(UART_NUM, PIN_DFPLAYER_TX, PIN_DFPLAYER_RX, -1, -1);
    if (ret != ESP_OK) return ret;
    ret = uart_driver_install(UART_NUM, UART_BUF_SIZE, UART_BUF_SIZE, 0, NULL, 0);
    if (ret != ESP_OK) return ret;

    vTaskDelay(pdMS_TO_TICKS(200));

    xTaskCreate(dfplayer_task, "dfplayer_rx", 2048, NULL, 5, NULL);
    ESP_LOGD(TAG, "DFPlayer 초기화 완료");
    return ESP_OK;
}

esp_err_t dfplayer_play(uint8_t track) {
    if (track < 1) return ESP_ERR_INVALID_ARG;
    return dfplayer_send_cmd(DFPLAYER_CMD_PLAY, 0, track);
}

esp_err_t dfplayer_play_loop(uint8_t track) {
    if (track < 1) return ESP_ERR_INVALID_ARG;
    return dfplayer_send_cmd(DFPLAYER_CMD_PLAYBACK_MODE, 0, track);
}

esp_err_t dfplayer_set_volume(uint8_t vol) {
    if (vol > 30) vol = 30;
    return dfplayer_send_cmd(DFPLAYER_CMD_VOLUME, 0, vol);
}

esp_err_t dfplayer_stop(void) {
    return dfplayer_send_cmd(DFPLAYER_CMD_STOP, 0, 0);
}

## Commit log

2026-07-11 Initial commit: ESP32-C3 RC tank with BLE gamepad (Bluepad32).
    Port M3Stuart RC tank firmware to ESP-IDF v5.5.2 with DRV8833 tracks, SG90 turret, DFPlayer, and custom Simple HOG path for GamePadPlus V3 / ShanWan BM-769.
2026-07-11 Repurpose headlight GPIO as gatling LED and remove headlight control.
    Blink GPIO6 at 75ms for machine gun fire like panzer4, keep cannon LED on GPIO1 only, and update the README.
2026-07-11 Improve cannon recoil: correct reverse, delay after LED/SFX, shorter push.
    Fire starts LED and sound first, then kicks back after 350ms with fixed positive motor direction and non-blocking control.
    [main.c]
2026-07-11 Slow turret, idle servo detach, and document cannon/turret behavior.
    Rate-limit turret to 1 deg/120ms, detach servo after 3s idle and reattach on D-pad. README covers fire sequence and servo attach policy.
2026-07-11 Add panzer4-style track accel/decel ramp and start-speed floor.
    Smooth track drive over ~1s to max with faster decel; bypass ramp for recoil and disconnect stop. Document stick ramp behavior in README.
2026-07-11 Fix turret jump when gamepad connects.
    Clear pad inputs on ready, ignore controls for 500ms after connect, and attach the turret servo only when the angle actually changes so reconnect does not re-drive PWM to the stored angle.
    [main.c]
2026-07-11 Set cannon recoil delay to 250ms.
    Shorten RECOIL_DELAY_MS after LED/SFX before track kickback; update README.
    [main.c]
2026-07-11 Add 3D print parts and PCB schematic assets.
    Include STEP models under 3dp/ and M3 Stuart schematic under pcb/, and document them in the README.
    [Idler.step, Motor Guide 2mm.step, Motor Guide 3mm D.step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]
2026-07-11 Attach turret servo only while gamepad is connected.
    Skip servo PWM at boot, attach on connect and detach on disconnect or idle. Document the lifecycle in the README.
    [main.c]
2026-07-11 Center turret servo when gamepad connects.
    On connect, set the turret to 90 degrees while attaching the servo PWM.
2026-07-11 Center turret with gamepad Start button.
    Map MISC_BUTTON_START to set the servo to 90 degrees on press edge; document in README.
